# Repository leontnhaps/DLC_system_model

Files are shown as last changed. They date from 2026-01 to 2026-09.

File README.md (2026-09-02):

# Camera-Guided Multi-Receiver Optical Wireless Power Transfer Testbed

<p align="center">
  <b>Receiver Detection · Multi-Object Tracking · Laser Pointing · Charging Scheduling</b>
</p>

This repository presents a research testbed for **laser-based Optical Wireless Power Transfer (OWPT)** in a single-transmitter, multi-receiver environment.

The platform integrates:

- camera-based receiver detection,
- pan-tilt workspace scanning,
- multi-object tracking,
- laser pointing,
- receiver-state recognition,
- time-division charging,
- and adaptive charging scheduling.

The system was developed as an experimental platform for research on **multi-receiver OWPT scheduling for wireless sensor and IoT networks**.

---

# 1. Overview

In a single-transmitter multi-receiver OWPT system, a laser transmitter must sequentially deliver energy to multiple receivers.

Because the available charging time is limited, the scheduling policy determines how much charging time is allocated to each receiver.

The research conducted with this platform was developed in two stages.

### Stage 1 — Receiver-State-Based Scheduling

The receiver battery state is represented using a **3-bit LED combination**.

The transmitter detects the receiver position and LED state through a camera and allocates more charging time to receivers with lower energy states.

```text
Receiver Scanning
        ↓
Receiver Detection
        ↓
Receiver Identification
        ↓
Battery-State Recognition
        ↓
Laser Pointing
        ↓
Charging-Time Allocation
        ↓
Sequential Optical Power Transfer
```

### Stage 2 — Battery and Energy-Transfer-Efficiency-Based Scheduling

Battery state alone does not represent the actual OWPT receiving condition.

Received optical power can vary due to:

- Tx–Rx distance,
- laser beam spreading,
- pointing error,
- and other optical channel conditions.

Therefore, the scheduling algorithm was extended to jointly consider:

```text
Battery State
      +
Energy Transfer Efficiency
      ↓
Priority Score
      ↓
Adaptive Charging-Time Allocation
```

---

# 2. System Architecture

The experimental platform follows a three-layer architecture.

```mermaid
graph LR

    GUI["PC GUI / Compute"]
    SERVER["Relay Server"]
    PI["Raspberry Pi Agent"]
    DRIVER["Pan-Tilt Driver"]
    CAMERA["Camera"]
    LASER["850-nm Laser"]

    RX1["Rx 1"]
    RX2["Rx 2"]
    RX3["Rx 3"]
    RXN["Rx N"]

    GUI -->|CTRL JSONL| SERVER
    SERVER -->|CTRL JSONL| PI

    PI -->|Events / Images| SERVER
    SERVER -->|Events / Images| GUI

    PI -->|UART| DRIVER
    PI -->|CSI| CAMERA
    PI -->|GPIO| LASER

    LASER --> RX1
    LASER --> RX2
    LASER --> RX3
    LASER --> RXN
```

The **PC** performs computational tasks including:

- image processing,
- YOLO inference,
- multi-object tracking,
- target position estimation,
- pointing control,
- and scheduling.

The **Raspberry Pi** controls:

- the camera,
- pan-tilt hardware,
- laser,
- IR-CUT module,
- and communication with the PC.

---

# 3. Experimental OWPT Testbed

<p align="center">
  
</p>

> `assets/testbed_overview.png`  
> Recommended image: experimental environment and Tx/Rx layout from the OWPT scheduling experiment.

The experimental OWPT system consists of:

### Transmitter

- laser power-transfer module,
- pan-tilt camera platform,
- camera,
- control unit,
- Raspberry Pi,
- and pointing controller.

### Receiver

Each receiver contains:

- photovoltaic cell,
- battery,
- retroreflective marker,
- battery-state LED module,
- and receiver electronics.

The transmitter identifies the position and state of each receiver using the camera and sequentially transfers optical power using time-division charging.

---

# 4. Receiver Scanning

The pan-tilt platform scans the target area using a predefined angular grid.

For each pan-tilt position, the system captures:

```text
LED ON Image
LED OFF Image
```

and calculates:

```text
Diff = |Image_ON - Image_OFF|
```

Differential imaging suppresses static background components and enhances receiver-related optical features.

The resulting image is processed by the receiver-detection algorithm.

---

# 5. Receiver Detection

Receiver candidates are detected using an **Ultralytics YOLO** model.

The current implementation supports:

- full-image inference,
- tiled inference,
- overlapping tiles,
- confidence filtering,
- Non-Maximum Suppression,
- and GPU acceleration when available.

The detection results contain:

```text
Bounding Box
Confidence
Class
Image Coordinate
Pan Angle
Tilt Angle
```

---

# 6. Multi-Object Tracking

A physical receiver may appear in multiple neighboring scan images.

Therefore, detections obtained from different pan-tilt positions must be associated with the same receiver.

The tracking module uses:

- HSV histogram features,
- grayscale histogram features,
- spatial grid-based feature extraction,
- cosine similarity,
- neighboring scan-frame candidates,
- and Hungarian assignment.

Each identified receiver is assigned a persistent:

```text
track_id
```

Similar tracks can also be merged after the scanning stage.

---

# 7. Target Position Estimation

After scanning, the detected image coordinates are mapped to pan and tilt angles.

For horizontal motion:

```text
cx = a · pan + b
```

For vertical motion:

```text
cy = e · tilt + f
```

where:

- `cx`, `cy` denote receiver image coordinates,
- `pan`, `tilt` denote transmitter angles.

The angle at which the receiver reaches the image center is estimated from the fitted relationships.

```text
Scan Detections
      ↓
Pixel-Angle Relationship
      ↓
Pan / Tilt Estimation
      ↓
Initial Target Point
```

This provides the coarse pointing position for each receiver.

---

# 8. Closed-Loop Laser Fine Pointing

After coarse pointing, the system performs closed-loop laser alignment.

The camera detects:

```text
Receiver Target Position
          +
Laser Spot Position
```

The pixel-domain error is calculated as:

```text
error_x = target_x - laser_x

error_y = target_y - laser_y
```

The error is converted into an angular correction:

```text
Δpan  = K_pan  × error_x

Δtilt = K_tilt × error_y
```

The process is repeated until the pointing error falls below the defined convergence threshold.

```text
Capture
   ↓
Detect Receiver
   ↓
Detect Laser
   ↓
Calculate Error
   ↓
Pan/Tilt Correction
   ↓
Repeat
```

<p align="center">
  
</p>

> Recommended image: pointing debug result showing the detected target, laser position, and pointing error.

---

# 9. Receiver-State Representation

Each receiver represents its battery state using three LEDs.

The LED states correspond to a 3-bit value:

```text
R B G
```

where:

```text
ON  = 1
OFF = 0
```

Therefore, eight discrete receiver states can be represented:

```text
000
001
010
011
100
101
110
111
```

with:

```text
000 → lowest state

111 → highest state
```

The transmitter identifies the LED combination using its camera.

---

# 10. Scheduling Methods

## 10.1 Round-Robin Scheduling

The conventional Round-Robin scheduler allocates the same charging time to every receiver.

For:

```text
N       = number of receivers
T_frame = scheduling-frame duration
```

the charging duration is:

```text
t_i = T_frame / N
```

Thus:

```text
Rx1 → Rx2 → Rx3 → ... → RxN
```

receives equal temporal access to the laser transmitter.

---

## 10.2 Receiver-State-Based Scheduling

The first proposed method allocates charging time according to the receiver state.

Let:

```text
d_i(k) ∈ {0, ..., 7}
```

represent the receiver's 3-bit state.

The charging coefficient is:

```text
b_i(k) = (8 - d_i(k)) / 8
```

A receiver with a lower state therefore obtains a larger charging coefficient.

The charging time is allocated as:

```text
               b_i(k-1)
t_i(k) = --------------------- × T_frame
          Σ b_j(k-1)
```

Thus:

```text
Lower receiver state
        ↓
Larger coefficient
        ↓
Longer charging duration
```

---

# 11. Experimental Evaluation of Receiver-State-Based Scheduling

The indoor experiment used four receivers.

| Parameter | Value |
|---|---:|
| Number of receivers | 4 |
| Tx–Rx distance | 4.5–6.0 m |
| Number of frames | 8 |
| Frame duration | 240 s |
| Initial states | 100 / 101 / 110 / 101 |

For Round-Robin:

```text
Rx1 = 60 s
Rx2 = 60 s
Rx3 = 60 s
Rx4 = 60 s
```

For the proposed scheduler:

```text
Rx1 = 80 s
Rx2 = 60 s
Rx3 = 40 s
Rx4 = 60 s
```

The lowest-state receiver therefore receives the longest charging duration.

---

## Battery-Voltage Experiment

<p align="center">
  
</p>

> Recommended image: normalized battery-voltage trajectories from the multi-receiver scheduling experiment.

The most significant difference was observed for **Rx1**, which had the lowest initial receiver state.

Approximate voltage change:

| Receiver | Round-Robin | Proposed |
|---|---:|---:|
| Rx1 | −5 mV | **+5 mV** |
| Rx2 | Similar trend | Similar trend |
| Rx3 | −5 mV | −10 mV |
| Rx4 | Similar trend | Similar trend |

Rx1 shows an approximately **10 mV difference** between the two scheduling strategies.

The proposed scheduler does not attempt to maximize the voltage of every receiver.

Instead, it redistributes the limited charging time to protect receivers with relatively low energy states and reduce imbalance among receivers.

---

# 12. Image-Based Energy Transfer Efficiency Model

The second research stage considers that charging efficiency differs between receivers even when their battery states are identical.

To estimate the energy-transfer condition, laser ON/OFF images are used.

The laser intensity distribution is modeled as an elliptical Gaussian beam:

```text
                      (u-u0)^2   (v-v0)^2
s(u,v) = exp[-2( ---------------- + ---------------- )]
                         wu^2         wv^2
```

Experimentally estimated mean beam radii:

```text
w_u = 118.14 px

w_v = 124.51 px
```

<p align="center">
  
</p>

The laser intensity incident on the PV-cell area can then be estimated from the camera image.

---

# 13. Regression-Based Received-Power Estimation

A regression model is used to estimate the relationship between image-based optical intensity and measured PV output voltage.

The adopted shifted quadratic model is:

```text
V_i = a(x_i - b)^2 + c
```

where:

- `x_i` is the image-based intensity value,
- `V_i` is the predicted PV voltage.

The fitted coefficients used in the study were approximately:

```text
a = 1.51
b = 0.01
c = 0.03
```

The predicted charging power is then calculated using the estimated voltage.

---

# 14. Battery and Energy-Transfer-Efficiency-Based Scheduling

The second proposed scheduler combines two factors:

```text
Battery State        → B_i

Transfer Efficiency  → C_i
```

The charging-efficiency coefficient is calculated from the inverse predicted charging power:

```text
          1 / P_i
C_i = ----------------
       Σ (1 / P_j)
```

The scheduling priority becomes:

```text
Score_i(k) = B_i(k-1) × C_i
```

and the charging duration is:

```text
                 Score_i(k)
t_i(k) = ----------------------------- × T_frame
           Σ Score_j(k)
```

Consequently, a receiver receives higher priority when it has:

```text
Low Battery State
        +
Low Energy Transfer Efficiency
```

This allows the scheduler to account not only for energy deficiency but also for differences in the actual optical receiving environment.

---

# 15. Simulation Results

The scheduling methods were compared using **First Node Death (FND)** as the network-lifetime metric.

FND is defined as the time at which the battery level of the first sensor node falls below the predefined threshold.

### Simulation Parameters

| Parameter | Value |
|---|---:|
| Number of sensor nodes | 4 |
| Monte-Carlo trials | 100 |
| Tx–Rx distance | 5–10 m |
| Battery capacity | 12960 J |
| FND threshold | 12.5% |
| Frame duration | 240 s |
| Node power consumption | 50 mW |

---

## Average First Node Death Time

<p align="center">
  
</p>

| Scheduling Method | Average FND |
|---|---:|
| No Charging | 3780 min |
| Round-Robin | 5286 min |
| Receiver-State-Based | 5352 min |
| **Battery + Transfer-Efficiency Proposed** | **5553 min** |

The proposed method achieved the longest average network lifetime.

Relative improvement:

```text
vs. No Charging
+46.9%

vs. Round-Robin
+5.1%

vs. Receiver-State-Based Scheduling
+3.8%
```

This result shows that incorporating the actual energy-transfer condition into scheduling can improve network lifetime beyond a scheduler based only on receiver state.

---

# 16. Research Progression

The overall research progression implemented in this repository can be summarized as:

```text
Equal Charging
Round-Robin
      ↓
Receiver-State Recognition
      ↓
Receiver-State-Based Scheduling
      ↓
Image-Based Beam Modeling
      ↓
Energy Transfer Efficiency Estimation
      ↓
Battery + Efficiency Scheduling
```

The system therefore evolved from a simple time-division OWPT testbed into a camera-guided scheduling platform capable of considering both:

```text
Receiver Energy State
           +
Physical OWPT Transfer Condition
```

---

# 17. Repository Structure

```text
.
├── Com/
│   ├── Com_main.py
│   ├── app/
│   ├── infra/
│   ├── ui/
│   ├── vision/
│   ├── workflows/
│   ├── scheduling/
│   └── tests/
│
├── Server/
│   └── Server_main.py
│
├── Raspberrypi/
│   └── Rasp_main.py
│
├── Target/
│   └── RX/
│       └── RX.ino
│
├── Experiments/
│   ├── detection/
│   ├── tracking/
│   ├── pointing/
│   ├── beam_model/
│   └── scheduling/
│
├── Docs/
│   ├── system_architecture.md
│   ├── hardware_setup.md
│   └── experiment_setup.md
│
├── assets/
│   ├── testbed_overview.png
│   ├── pointing_result.png
│   └── results/
│       ├── battery_voltage_comparison.png
│       ├── beam_intensity_model.png
│       └── fnd_comparison.png
│
├── requirements.txt
├── LICENSE
└── README.md
```

---

# 18. Main Software Modules

| Module | Function |
|---|---|
| PC GUI | System control and experiment interface |
| YOLO Detector | Receiver detection |
| MOT | Receiver identification across scan positions |
| Scan Controller | Pan-tilt scan and image processing |
| Pointing | Target-angle estimation |
| Fine Aiming | Closed-loop laser alignment |
| Scheduling | Multi-receiver charging control |
| Relay Server | PC–Raspberry Pi communication |
| Raspberry Pi Agent | Physical hardware control |

---

# 19. Requirements

## PC

```bash
pip install numpy scipy opencv-python pillow ultralytics
```

Additional packages may be required depending on the experiment configuration.

---

## Raspberry Pi

```bash
pip install pyserial
```

The Raspberry Pi environment must also provide:

```text
picamera2
RPi.GPIO
```

---

# 20. Quick Start

## Step 1 — Start Relay Server

```bash
python Server/Server_main.py
```

Default ports:

| Connection | Port |
|---|---:|
| Raspberry Pi Control | 7500 |
| Raspberry Pi Images | 7501 |
| GUI Control | 7600 |
| GUI Images | 7601 |

---

## Step 2 — Start Raspberry Pi Agent

```bash
python3 Raspberrypi/Rasp_main.py
```

---

## Step 3 — Start PC GUI

```bash
python Com/Com_main.py
```

The GUI provides interfaces for:

- scanning,
- preview,
- manual pan-tilt control,
- laser control,
- pointing,
- and scheduling.

---

# 21. Experimental Output

A scan session produces:

```text
captures/
└── scan_YYYYMMDD_HHMMSS/
    ├── captured images
    ├── scan_*_detections.csv
    └── similarity_log_live.txt
```

Typical detection data include:

```text
pan_deg
tilt_deg
cx
cy
w
h
conf
cls
track_id
```

Additional fields may contain:

- LED-state estimates,
- receiver-state information,
- final pointing coordinates,
- and other experimental measurements.

---

# 22. Key Research Contributions

This project demonstrates an integrated framework for:

1. **camera-guided detection of multiple optical-power receivers,**
2. **receiver identification during pan-tilt scanning,**
3. **automatic laser pointing,**
4. **visual receiver-state recognition,**
5. **adaptive time-division optical power scheduling,**
6. **image-based estimation of OWPT energy-transfer conditions,**
7. **and lifetime-oriented scheduling for wireless sensor networks.**

---

# 23. Future Work

Possible extensions include:

- dynamic receiver tracking,
- mobile receiver charging,
- UAV optical wireless power transfer,
- receiver-side PV orientation control,
- simultaneous lightwave information and power transfer,
- and learning-based transmitter / receiver control.

---

# License

This project is released under the MIT License.

See `LICENSE` for details.

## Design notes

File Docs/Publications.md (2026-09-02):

# 📚 작성 논문 (Publications)

본 프로젝트로 작성된 연구 논문 목록입니다.

---

## 1. 레이저 기반 에너지 전송을 위한 픽셀-각도 맵핑 방식의 Pan-Tilt 카메라 제어

**학회**: 한국통신학회 (KICS)  
**연도**: 2025  

**요약**:  
레이저 기반 무선 에너지 전송 시스템에서 픽셀 좌표와 Pan-Tilt 각도 간 맵핑을 통한 정밀 제어 기법에 대한 연구입니다. 선형 회귀 기반 coarse alignment와 레이저 피드백 기반 fine adjustment 알고리즘이 제안되었습니다.

---

## 2. 광무선 전력 전송을 위한 Pan-Tilt 카메라 스캔 시스템에서 다중 객체 추적기법

**학회**: 한국통신학회 (KICS)  
**연도**: 2026  

**요약**:  
Pan-Tilt 카메라 기반 광무선 전력 전송(Optical Wireless Power Transfer) 시스템에서 스캔 중 다중 객체를 추적하는 기법에 대한 연구입니다. 헝가리안 알고리즘을 활용한 최적 매칭 및 특징 기반 객체 추적 알고리즘이 제안되었습니다.

---

## 3. Battery-Aware Scheduling for Multi-Receiver Laser Wireless Power Transfer in IoT Systems

**학회**: International Conference on Ubiquitous and Future Networks (ICUFN)  
**연도**: 2026  

**요약**:  
단일 송신기(Tx)와 다중 수신기(Rx)로 구성된 레이저 기반 OWPT 환경에서 각 Rx의 배터리 상태를 고려하는 충전 스케줄링 기법을 제안한 연구입니다. 각 Rx는 배터리 상태를 3-bit LED 조합으로 표시하고, Tx는 카메라를 이용해 이를 인식합니다. 이전 프레임에서 인식한 배터리 상태를 기반으로 현재 프레임의 충전 시간을 차등 할당하여, 배터리 상태가 낮은 Rx에 더 긴 충전 시간을 제공합니다. 실제 실내 레이저 기반 OWPT 테스트베드 실험을 통해 Round-Robin 방식보다 저배터리 Rx의 전압 저하를 완화하고 Rx 간 에너지 불균형을 줄일 수 있음을 확인하였습니다.

---

## 4. 무선 센서 네트워크를 위한 배터리 및 에너지 전송 효율 기반 레이저 무선 전력 전송 스케줄링 기법

**영문 제목**: Battery and Energy Transfer Efficiency Based Laser Wireless Power Transfer Scheduling for Wireless Sensor Networks  

**학회**: 한국통신학회 하계종합학술발표회 (KICS)  
**연도**: 2026  

**요약**:  
기존 배터리 상태 기반 OWPT 스케줄링을 확장하여, 각 센서 노드의 배터리 상태뿐만 아니라 실제 에너지 전송 효율을 함께 고려하는 충전 스케줄링 기법을 제안한 연구입니다. 레이저 ON/OFF 이미지의 차분과 Gaussian beam 모델을 이용해 각 수신기의 광 세기를 추정하고, 회귀 모델을 통해 PV cell의 출력 전압과 예상 충전 전력을 계산합니다. 이후 배터리 상태와 에너지 전송 효율을 결합한 우선도 점수를 기반으로 충전 시간을 동적으로 할당합니다. 시뮬레이션 결과 제안 방식은 평균 First Node Death(FND) 시간이 5553 min으로 나타났으며, Round-Robin 대비 약 5.1%, 기존 Battery-Aware 방식 대비 약 3.8%의 성능 향상을 보였습니다.

---

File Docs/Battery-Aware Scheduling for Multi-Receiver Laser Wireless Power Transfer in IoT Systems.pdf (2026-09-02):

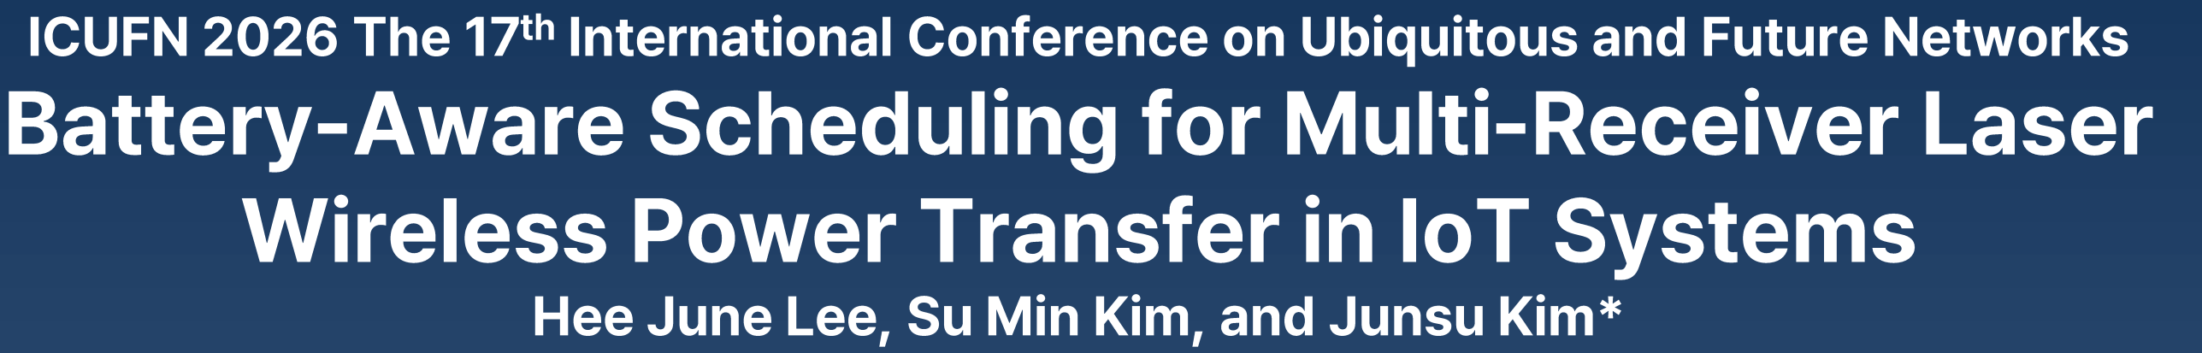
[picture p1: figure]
Wireless Power Transfer in IoT Systems

- Wireless Sensor Networks (WSNs)
- WSNs rely on battery - powered sensor nodes
- Battery depletion limits long -term network operation
- Optical Wireless Power Transfer (OWPT)
- OWPT can remotely supply energy to sensor nodes
- Laser - based OWPT enables selective power transfer due to its high directionality and narrow beam divergence
- Need for Multi- Receiver (Rx) Scheduling
- If Rxs have different battery states, low- battery Rxs should be charged with higher priority
- Therefore, efficient charging -time allocation is required to mitigate energy imbalance among Rxs

## Introduction

## ICUFN 2026 The 17 th International Conference on Ubiquitous and Future Networks

Battery -Aware Scheduling for Multi | - Receiver Laser
Hee June Lee, Su Min Kim, and Junsu | Kim*

## Tech University of Korea (TU Korea)

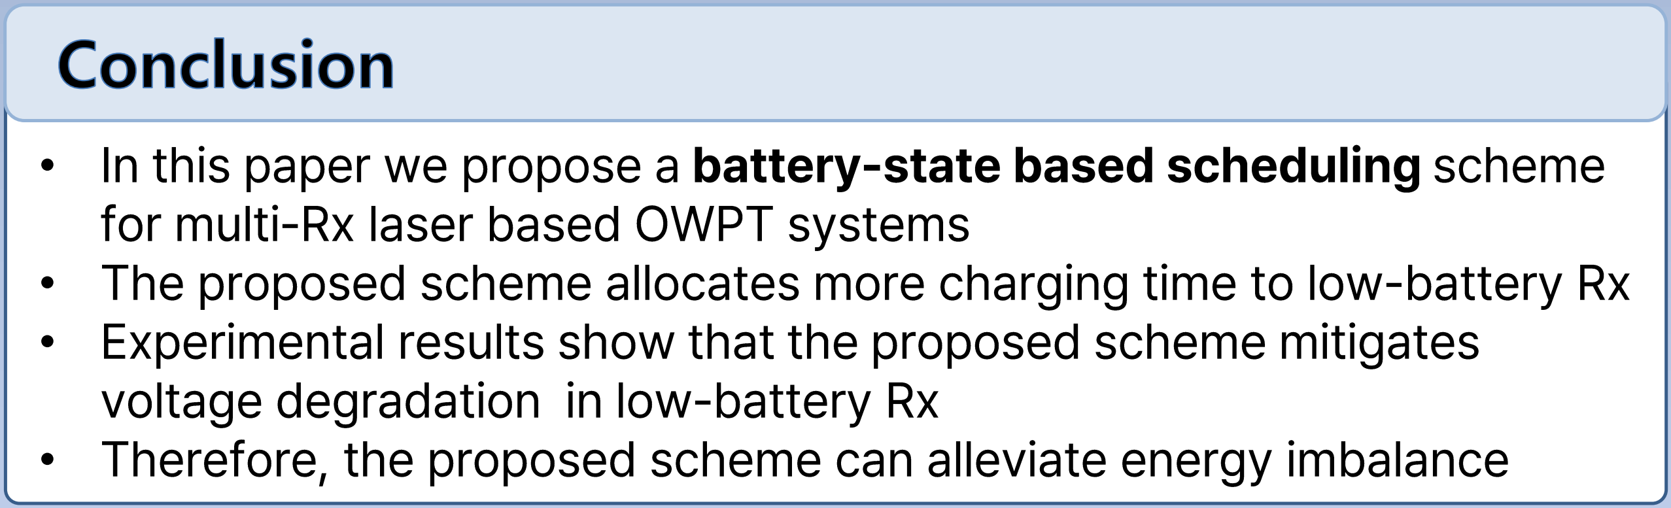
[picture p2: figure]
for multi-Rx laser based OWPT systems; voltage degradation; in low-battery Rx; Conclusion

This work was supported in part by the Institute of Information & Communications Technology Planning & Evaluation(IITP)-ICAN(ICT Challenge and Advanced Network of HRD) grant funded by the Korea government(Ministry of science and ICT)(IITP-2026-RS-2022-00156326, 50) and in part by the Commericalization Promotion Agency for R&D Outcomes (COMPA) funded by the Korea government (MSIT) (RS-2024-00456813).

- Laser - Based OWPT System Testbed
- The system consists of a | single fixed transmitter (Tx) | and multiple
fixed Rxs
- The Tx includes a laser power transfer module, a pan -tilt camera, and a control unit
- Each Rx consists of a PV cell, battery, retroreflective film, and 3 -blit LED module
(a) (b)
- System Operation
- The Tx identifies Rx positions and battery states using camera - based recognition
- Each Rx represents its battery state using a 3 - bit LED combination
- The operation consists of two stages, scanning and scheduling
- Time -division charging is performed, where only one Rx is charge at a time
(a) (b)

## System Model

Abstract
This work proposes a scheduling scheme for a singe | -transmitter (Tx) multi -receiver (Rx) laser -based optical wireless power trans | fer (OWPT) system. Each Rx represents
its battery state using a 3 -bit LED combination, which is recognized by the Tx through a camera. Based on the battery | -state info rmation obtained in the previous frame,
the charging time is adaptively allocated so that | Rxs with lower battery states receive more charging time. Experimental results show that proposed scheme mitigates
voltage degradation in low -battery Rxs and alleviates energy imbalance among | Rxs .
- Proposed Battery - State Based Scheduling
- Each Rx represents its | battery state using a 3 -blit LED combination
- The Tx recognizes the battery state of each Rx through | camera - based
recognition
- A lower battery state produces a larger charging coefficient
- Charging time is allocated according to the coefficient ratio in each frame
- Therefore, low-battery Rxs receive more charging time than high -battery Rxs

### - Conventional Round - Robin Scheduling

- Equal charging time is allocated to all Rxs in each frame
- However, it does not consider the battery state of each Rx

## Proposed Scheme

- Experimental Setup
- A total of four Rxs are evaluated using a dataset acquired from the implemented indoor laser - based OWPT testbed
- The Tx -Rx distances range from 4.5 m to 6 m
- The frame duration is set to 240 s, and 8 frames are evaluated
- The initial 3 -bit battery states are set to 100, 101, 110, and 101
- Charging - Time Allocation
- In the round -robin scheme , 60 s is allocated to each Rx
- In the proposed scheme , charging times of 80, 60, 40 and 60 s are allocated according to the battery state
- Rx1 is allocated the longest charging time because it had the lowest initial battery state
- Result Analysis
- In the proposed scheme, Rx1 voltage | increased by approximately 5 mV
- In the round -robin scheduling, Rx1 voltage | decreased by approximately

### 5 mV

- The proposed scheme mitigates voltage degradation in the low | -battery
- This result shows that adaptive charging | -time allocation can alleviate
energy imbalance | among Rxs

## Performance Evaluation

Laser wavelength | 850 nm
Number of Rxs | 4
Tx -Rx distance for each Rx | 4.5~6 m
Number of frames | 8
Duration of a single frame | 240 s
- In this paper we propose a | battery -state based scheduling | scheme
- The proposed scheme allocates more charging time to low | -battery Rx
- Experimental results show that the proposed scheme mitigates
- Therefore, the proposed scheme can alleviate energy imbalance

Table. 1. System parameters .

Fig. 1. Photographs of the Tx and Rx modules used in the experimental laser - based OWPT testbed : (a) Tx, (b) Rx .

Fig. 2. Experimental laser - based OWPT testbed: (a) Photograph of the indoor test environment, (b) Layout of the experimental laser based OWPT testbed.

Fig. 3. Comparison of normalized battery | - voltage trajectories of
the Rxs under the proposed and round | -robin scheduling schemes.

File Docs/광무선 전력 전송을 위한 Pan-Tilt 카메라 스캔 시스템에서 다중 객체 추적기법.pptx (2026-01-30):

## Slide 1

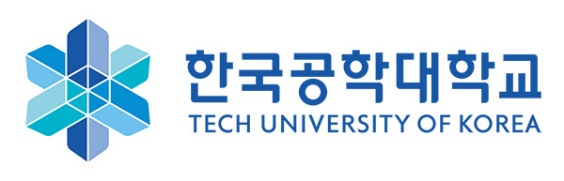
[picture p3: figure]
한국산업기술대학교, 한국공학대학교로 교명 변경하고 비전 선포식 개최-아이씨엔매거진

광무선 전력 전송을 위한 Pan-Tilt 카메라
스캔 시스템에서 다중 객체 추적 기법

2026-02-06
이희준, 빈경민, 김수민, 김준수*
gmlwns2279@tukorea.ac.kr
Dept. of IT Semiconductor Convergence Engineering, TUK
Intelligent Connected-Things (ICon) Lab

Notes: 안녕하세요. '광무선 전력 전송을 위한 Pan-Tilt 카메라 스캔 시스템에서 다중 객체 추적 기법'에 대해 김준수 교수님 지도학생 석사 1년차 이희준입니다. 발표 시작하겠습니다.

## 목차

- 서론
- System model
- 제안하는 기법
- 스캔 토폴로지 기반 인접 후보군 탐색 기법
- 정보 보존형 격자 히스토그램 기법

- 성능평가
- 결론

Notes: 목차입니다.

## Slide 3

- 문제 정의
  - 광무선 전력 전송(OWPT)시 수신부의 정확한 위치 파악 및 지속적 추적 필수[1].
  - 넓은 공간을 저비용으로 커버하기위한 pan-tilt 카메라 사용[2].
  - 넓은 영역 커버를 위해 pan-tilt를 높은 각도로 스캔 시, 프레임 간 타겟 위치가 불연속적으로 급변함.
  - 기존 다중 객체 추적 알고리즘(SORT)는 IoU기반 추적 알고리즘이기에 본 시스템에서 추적을 실패함[3].
- 해결 방안
  - 스캔 토폴로지 기반 인접 후보군 탐색 기법 : 물리적 위치 대신 스캔 경로의 논리적 인접성을 활용한 후보군 탐색 기법 제안.
  - 정보 보존형 격자 히스토그램 기법 : 시점 변화 및 정보 보존에 강인하도록 격자 분할 기반의 색상/형태 히스토그램 코사인 매칭 적용.

[1] S. A. H. Mohsan, H. Qian, and H. Amjad, "A Comprehensive Review of Optical Wireless Power Transfer Technology," Frontiers of Information Technology & Electronic Engineering, vol. 24, no. 6, pp. 767-800, June 2023.
[2] H. J. Lee, G. M. Been, S. M. Kim, and J. Kim, “Pan-Tilt Camera Control with Pixel-Angle Mapping for Laser Energy Transfer”, in Proc. KICS Fall Conf., Nov. 2025.
[3] A. Bewley, Z. Ge, L. Ott, F. Ramos, and B. Upcroft, "Simple online and realtime tracking," in Proc. IEEE ICIP, Sep. 2016.

서론

1

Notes: 최근 IoT 기기의 전원 공급을 위해 광무선 전력 전송(OWPT) 기술이 주목받고 있습니다.
이 시스템의 핵심은 수신부의 위치를 정확히 파악하고 지속적으로 추적하는 것입니다.
저희는 넓은 공간을 저비용으로 커버하기 위해 Pan-Tilt 카메라를 도입했습니다.
다중 타겟인 상태에서, 넓은 영역을 15도씩 빠르게 스캔하다 보니, 프레임 간 타겟의 위치가 불연속적으로 급변하는 문제가 발생했습니다.
이로 인해 기존의 위치 기반 추적 알고리즘인 SORT 등은 추적에 실패하게 됩니다.
이를 해결하기 위해 저희는 물리적 거리 대신 스캔 토폴로지 기반 인접 후보군 탐색 기법 , 정보 보존형 격자 히스토그램 기법을 제안합니다.

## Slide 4

System model

송신부
- Pan-tilt 구동부, RGB 카메라, LED 모듈, 레이저 모듈 로 구성.
- Boustrophedon 패턴을 따라 15° 의 간격 으로 스캔 진행.
수신부
- 인식을 위한 빨간색 재귀반사필름, 에너지 변환을 위한 Solar cell 로 구성.
- 송신부로 부터 5~10 m 거리내에 4개 무작위 배치.

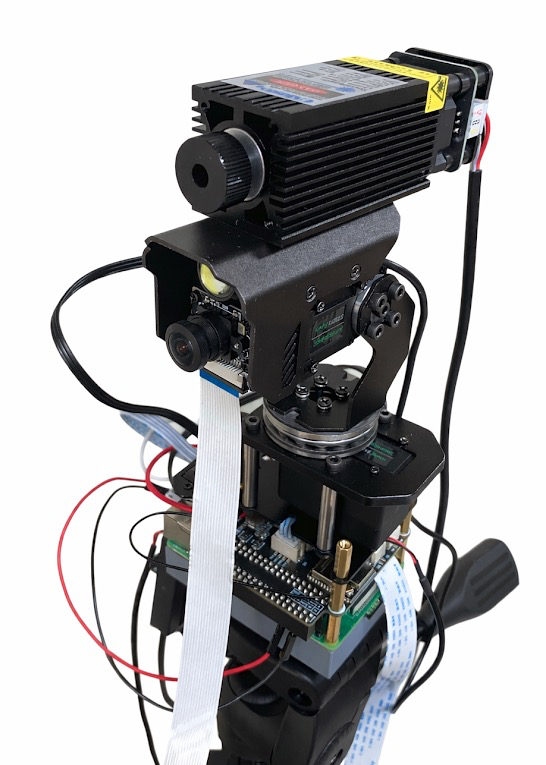
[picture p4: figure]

그림 1. 송신부

2

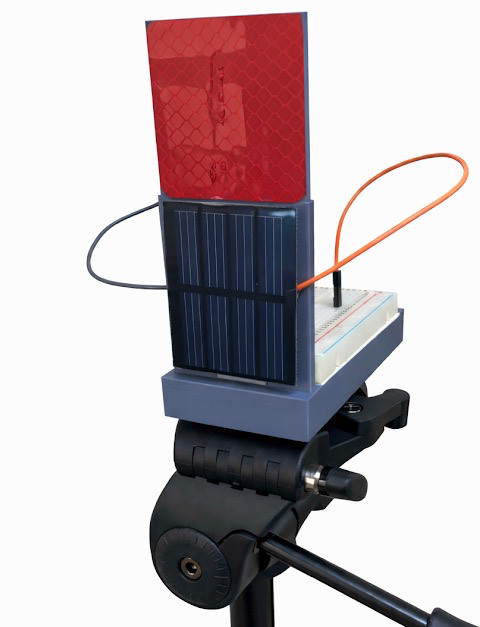
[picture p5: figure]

그림 2. 수신부

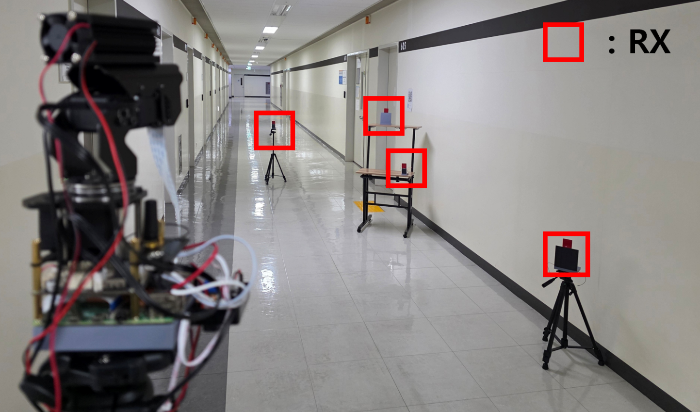
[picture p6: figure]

그림 3. 시스템 모델

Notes: 본 연구의 시스템 모델입니다.
송신부는 Pan-Tilt 구동부 위에 RGB 카메라와 레이저, LED 모듈이 결합된 형태이며,
효율적인 탐색을 위해 지그재그 형태인 Boustrophedon(부스트로페돈) 패턴으로 15도씩 이동하며 스캔합니다.
수신부는 5~10m 거리에 무작위로 배치되어 있으며,
인식을 돕기 위한 빨간색 재귀반사필름과 에너지를 전환 할 Solar cell 로 구성되어 있습니다.
수신부를 검출하는 방법은 사전에 재귀반사필름을 학습시킨 Yolo 모델을 통해 검출합니다.

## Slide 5

■ 스캔 토폴로지 기반 인접 후보군 탐색 기법

- 기존 알고리즘은 후보군의 최대 개수(max age)를 정한 후 후보군 생성.
- 수신부가 정적이므로 인접한 pan,tilt 일때 탐지될 확률이 높음.
- 최대 개수를 지정하는 대신 스캔 토폴로지의 인접성을 통한 비교 후보군 지정.
- 현재 스캔 인덱스를 (Pan_t ,Tilt_t ) 라 고 할때, 후보군 생성.
S={(Pan_(t−1) ,Tilt_t ),(Pan_t ,Tilt_(t−1) ),(Pan_(t−1) ,Tilt_(t−1) ),(Pan_(t−2) ,Tilt_t ),(Pan_(t+1) ,Tilt_(t−1) )}

3

스캔 토폴로지 기반 인접 후보군 탐색 기법

4 | 3 | 2 | 1 | (Pan_t ,Tilt_t )
5 | 6 | 7 | 8 | 9 | 10

그림 4. Max age =10 인 기존 알고리즘 후보군

| | (Pan_(t−2) ,Tilt_t ) | (Pan_(t−1) ,Tilt_t ) | (Pan_t ,Tilt_t )
| | | (Pan_(t−1) ,Tilt_(t−1) ) | (Pan_t ,Tilt_(t−1) ) | (Pan_(t+1) ,Tilt_t )

그림 5. 제안하는 기법의 후보군

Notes: 스캔 토폴로지 기반 인접 후보군 탐색 기법 입니다.
기존의 MOT 알고리즘은 최대 프레임 개수에 제한을두고 후보군을 비교하는 방식으로 진행이 됩니다.
저희 시스템에선 타겟이 정적임에 따라, 탐지가 되었을때 근처 pan, tilt 에서 탐지가 되었을 확률이 높습니다.
따라서 최대개수를 지정해 프레임을 비교하는 것이아니라 스캔 토폴로지의 인접성을 이용하여 후보군을 지정하여 비교 프레임 개수를 효율적으로 줄일 수 있습니다.
지정하는 후보군은 tilt 값이 그대로고 pan 값을 조정한 전프레임과 전전프레임, tilt 값을 조정한 토폴로지 기준 아래 프레임, pan, tilt 값을 둘다 조정한 대각선프레임 총 5개의 후보군을 지정하여 비교를 합니다.

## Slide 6

■ 1. 프레임 촬영 , 2. 수신부 탐지

4

정보 보존형 격자 히스토그램 기법

1. 프레임 촬영

2. 수신부 탐지

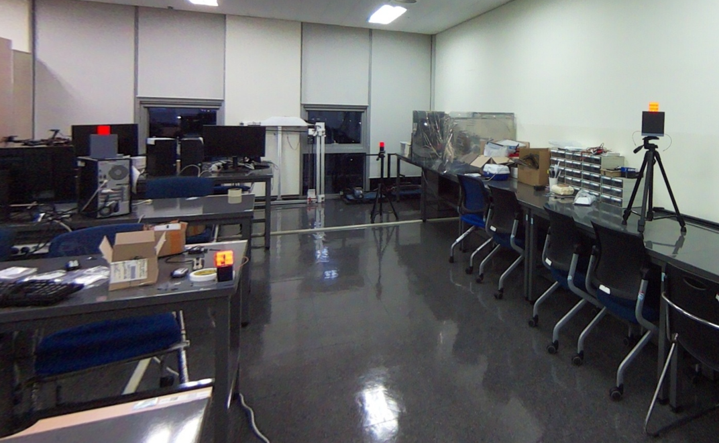
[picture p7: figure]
실내, 가구, 벽, 컴퓨터이(가) 표시된 사진 AI 생성 콘텐츠는 정확하지 않을 수 있습니다.

그림 6. 프레임 촬영 및 수신부 탐지

3. ROI

4. 격자 생성

5. 히스토그램 추출

6. 비교 및 최적 매칭

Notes: 비교하는 방식은 총 6단계로 이루어져 있습니다. 프레임 촬영, 객체 탐지, ROI, 격자 생성, 히스토그램추출 , 비교 및 최적 매칭 순으로 이루어 집니다.
우선 프레임촬영과 수신부탐지입니다.
각 지정된 스캔지점에서 촬영을하여 수신부를 탐지합니다.
재귀반사필름을 학습한 모델, yolo를 이용하여 수신부를 탐지합니다.
수신부가 탐지되지 않으면 스캔 경로에따라 프레임촬영을 이어서 합니다.

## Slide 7

■ 3. ROI , 4. 격자 생성

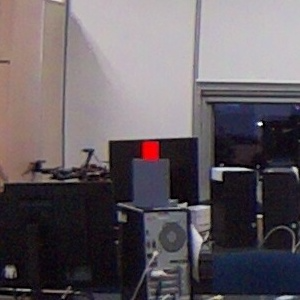
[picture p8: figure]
실내, 라우드스피커, 벽, 오디오 장비이(가) 표시된 사진 AI 생성 콘텐츠는 정확하지 않을 수 있습니다.

그림 7. 300x300 ROI

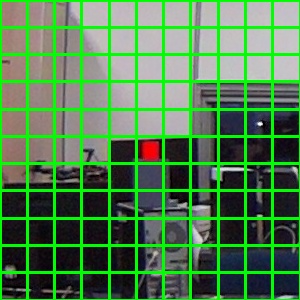
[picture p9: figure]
사각형, 스크린샷, 다채로움, 예술이(가) 표시된 사진 AI 생성 콘텐츠는 정확하지 않을 수 있습니다.

그림 8. 11x11 격자 생성

- ROI : 수신부 및 배경 정보를 추출하기위한 ROI 생성.
- 격자 생성 : 정보 추출 시, 공간정보를 보존하기 위한 격자 생성.

5

정보 보존형 격자 히스토그램 기법

1. 프레임 촬영

2. 수신부 탐지

3. ROI

4. 격자 생성

5. 히스토그램 추출

6. 비교 및 최적 매칭

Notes: ROI, 격자생성 단계입니다.
정보를 추출하기위해 탐지된 수신부의 중심으로 부터 300x300 ROI 를 합니다.
이후 ROI 에서부터 정보를 추출할때 공간정보를 보존하기위한 11x11 의 격자를 생성합니다.

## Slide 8

■ 5. 히스토그램 추출, 6. 비교 및 최적 매칭

- 히스토그램 추출 : 격자별 HSV, Grayscale 에서의 히스토그램 추출 및 특징 벡터 생성.
- 코사인 유사도 : 특징 벡터 간의 각도를 계산하여 유사도 측정.
Similarity(A,B) =(V_A ∙V_B)/(|V_A ||V_B |)
- 최적화 : 헝가리안 알고리즘을 사용하여 최적 매칭 수행[4].
- ID Assignment : 코사인 유사도 값이 일정 값 보다 낮을 때, 새로운 ID 부여.

[4] H. W. Kuhn, "The Hungarian method for the assignment problem," Naval Research Logistics Quarterly, vol. 2, no. 1-2, pp. 83-97, 1955. 6

정보 보존형 격자 히스토그램 기법

1. 프레임 촬영

2. 수신부 탐지

3. ROI

4. 격자 생성

5. 히스토그램 추출

6. 비교 및 최적 매칭

히스토그램 추출

특징 벡터

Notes: 나눠진 격자별로 비교를 위해 히스토그램을 추출하는데 추출하는영역은
HSV 에서의 HS, Grayscale 에서의 히스토그램을 추출하여 하나의 특징벡터로 결합합니다.
H(0~360 , 8) S(0~100 , 4), Gray(0~255, 16)
이후 스캔 토폴로지에 따른 후보군에서 뽑은 특징

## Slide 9

■ 평가지표

- IDSW(ID Switch) - 추적하는 타겟의 ID가 바뀌는 횟수
- ID Purity - 하나의 ID에서 가장 많은 빈도의 타겟이 차지하는 비율
- MOTA(MOT Accuracy) - 탐지성능과 IDSW를 종합한 표준 정확도. - MOTA= 1 − (∑_t (FN_t + FP_t + IDSW_t ))/(∑_t GT^t).
- AssA(Association Accuracy) - 올바른 ID가 유지된 시간 비율의 가중평균.

7

성능평가

t : 프레임 인덱스.
FN_t : t 에 서의 미검출 수.
FP_t : t 에 서의 오검출 수.
IDSW_t : ID 스위칭 수.
GT^t : t 에 존재하는 실제 타겟의 총 수.

1

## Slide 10

■ 검증 결과

- 실내 환경에서 5-10m 거리에 수신부를 배치하여 획득한 데이터 셋 활용.
- 표2는 KITTI test set 에대한 MOTA 결과표로 90%대의 결과를 보여줌[5].
- 제안하는 기법은 보다 쉬운 환경임에따라 보다 높은 MOTA 기록.

[5] X. Wang et al., "MCTrack: A Unified 3D Multi-Object Tracking Framework for Autonomous Driving," 2025 IEEE/RSJ International Conference on Intelligent Robots and Systems (IROS), Hangzhou, China, 2025 8

성능 평가

파라미터 | 값
실제 타겟 수 | 4 개
식별 타겟 수 | 10 개
MOTA(↑) | 94.5%
IDSW(↓) | 6회
ID Purity(↑) | 100%

표1. 검증결과

기법 | MOTA
MCTrack | 91.62%
CasTrack | 91.91%
RAM | 91.61%
OC-SORT | 90.28%
BiTrack | 91.52%

표2. 타 Method MOTA

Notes: 성능 평가입니다.
검증결과 실내 환경에서 4개의 수신부를 5~10m 거리에 배치하여 획득한 데이터셋으로 검증을 하였고.
결과는 표1과 같습니다.
표2는 타 MOT Mehod의 MOTA 결과인데 KITTI test set 에대한 지표입니다.
Kitti test set은 자율주행 을 위한 데이터 셋입니다.
저희가 제안하는 방식은 보다 쉬운환경임에따라 보다 높은 MOTA 결과를 얻은것을 확인할 수 있습니다.

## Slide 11

Method | ID Purity(↑) | IDSW(↓) | AssA(↑) | MOTA(↑)
스캔 토폴로지 기반 인접 후보군, 격자(11x11) | 100% | 6회 | 0.76 | 94.5%
스캔 토폴로지 기반 인접 후보군, 격자(5x5) | 75.5% | 1회 | 0.73 | 99.1%
스캔 토폴로지 기반 인접 후보군, 격자 미적용 | 32.7% | 2회 | 0.25 | 98.2%
Max age = 5, 격자(11x11) | 100% | 6회 | 0.58 | 94.5%
Max age = 5, 격자 미적용 | 31.8% | 2회 | 0.24 | 98.2%

- 격자의 정보보존 : 단일 히스토그램(Grid 미적용)은 정보의 부족으로 인한 객체 구분 실패로 인해, ID Purity매우 낮은 값 도출.
- 토폴로지 기반 후보군 : 트랙 파편화를 억제하여 높은 AssA 도출.
- 병합 오류 방지 : 일부 높은 MOTA 값은 낮은 비교 성능으로 인한 ID 병합에 의한 값.

9

성능 평가

표3. 제안 기법의 파라미터별 성능 평가

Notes: 제안 기법을 검증하기 위한 결과표입니다.
격자가 미적용되거나 조금 낮은 방식을 적용한 결과를보면 MOTA가 매우 높에 나온것을 확인할 수있습니다.
이는 격자 의 분류가 낮거나 미적용으로인해 객체의 정보부족으로 서로다른 객체를 구분하지 못하고 하나로 병합했기에 ID SW 값자체가 낮아 나온 결과입니다. 이는 ID Purity 를 보시면 객체를 구분하지못하고 병합해버려 비교적 낮은 값들이 나온것을 확인할수 있습니다.
스캔 토폴로지 기반 후보군을 적용을 비교하면 격자 미적용시에는 AssA 값이 차이가 많이 나지않지만 이는 객체를 비교하지 못하여 나온것이고, 격자 적용시를 비교하면 AssA 값이 오른것을 확인할 수 있습니다. 이는 동일하게 5개의 후보군을 비교를 했지만 스캔 토폴로지 기반 후보군이 보다 우수한 비교 후보군을 생성해 파편화를 억제한것을 확인할수있습니다.

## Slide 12

■ 결론, 향후 연구

결론
- 본 논문은 pan-tilt 카메라를 활용한 레이저 기반의 무선 전력 전송 시스템에서 다중 객체 추적 기법을 제안함.
- 스캔 토폴로지 기반 인접 후보군 탐색 기법을 통해 급격한 시점 변화에도 트랙 파편화를 억제하고 추적 안정성 확보.
- 격자 기반 히스토그램 코사인 유사도를 통해 시점/외형 변화에 강인한 추적 성능 확보.
- 실내 환경에서의 검증 결과 MOTA 94.5% 달성으로 안정적 추적 확인.
향후 연구
- Target 설계를 통한 IoT 기기 충전 시스템 연구.
- 정적인 Target 이 아닌 동적인 Target 시스템 에서의 추가 기법 고안.

10

결론

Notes: 결론입니다.

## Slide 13

Thank you

2026-02-06
이희준, 빈경민, 김수민, 김준수*
gmlwns2279@tukorea.ac.kr
Dept. of IT Semiconductor Convergence Engineering, TUK
Intelligent Connected-Things (ICon) Lab

마무리

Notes: 감사합니다.

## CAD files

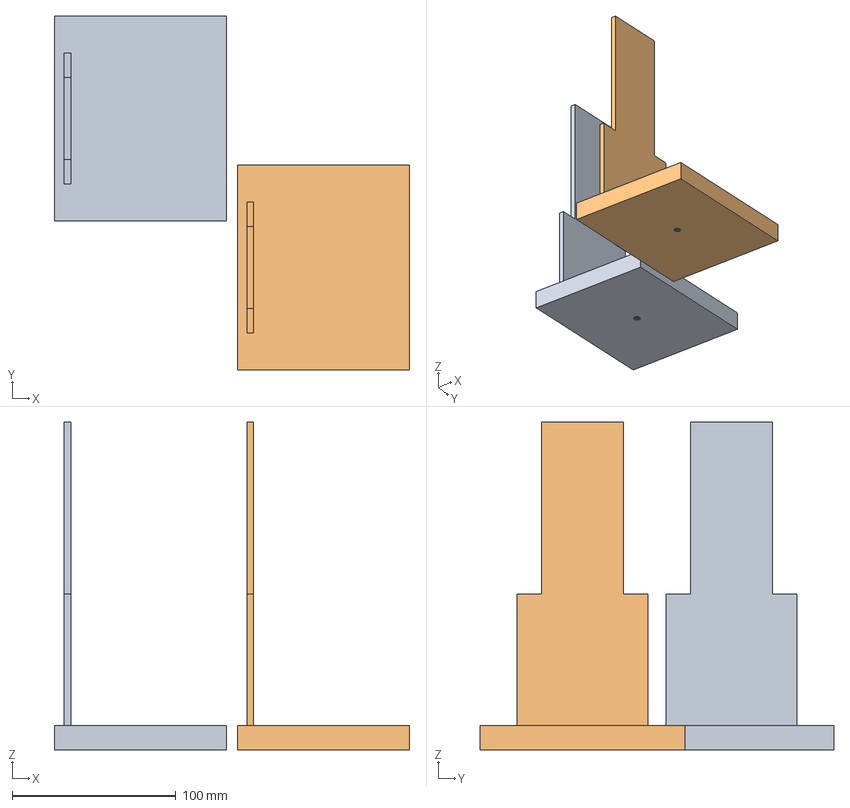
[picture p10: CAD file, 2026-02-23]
3D_printer/RX/8_8_RX/8_8_align.3mf
216.6 x 215.9 x 200.0 mm
Camera_LaserModule.stl x 2

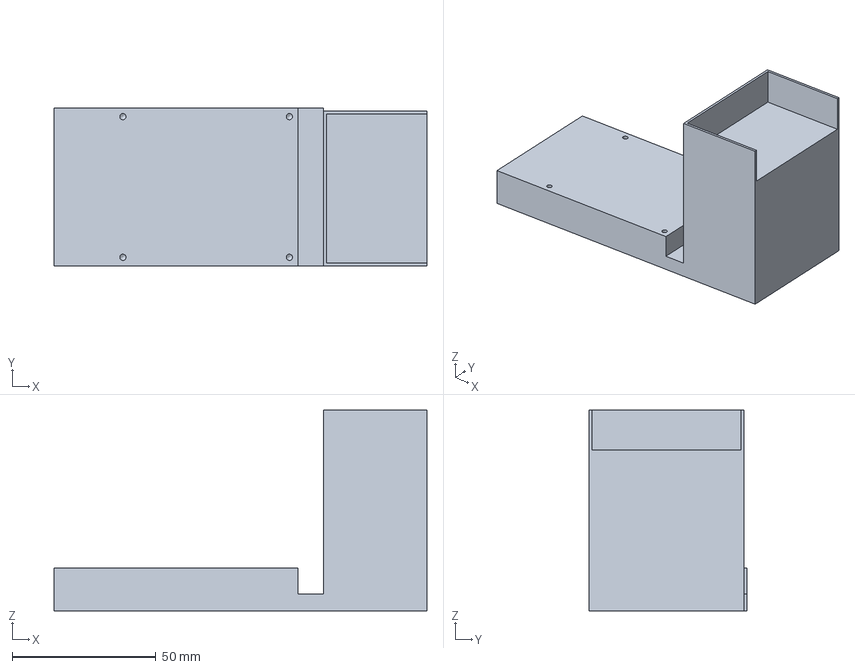
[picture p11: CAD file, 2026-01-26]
3D_printer/TX/TX_mount.3mf
129.9 x 55.0 x 70.0 mm

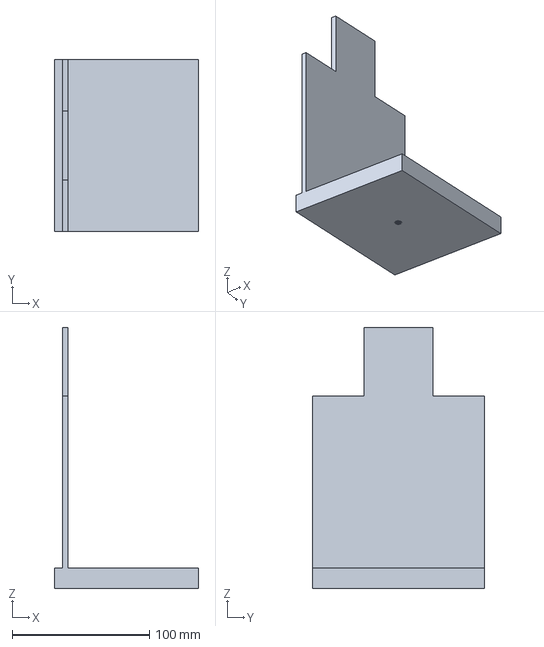
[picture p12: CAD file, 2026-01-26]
3D_printer/RX/12_12_RX/Target.3mf
105.0 x 125.1 x 190.0 mm

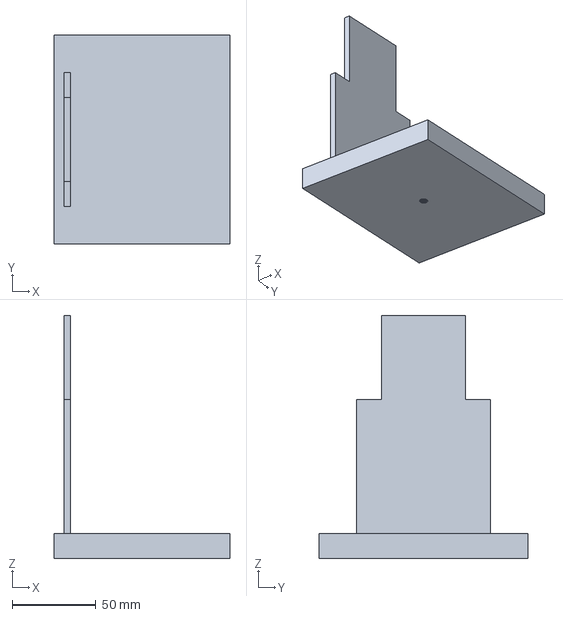
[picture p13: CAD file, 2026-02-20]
3D_printer/RX/8_8_RX/8_8test.3mf
105.0 x 125.0 x 145.0 mm

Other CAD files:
3D_printer/RX/12_12_RX/Target.gcode.3mf
3D_printer/RX/8_8_RX/8_8_align.gcode.3mf
3D_printer/TX/TX_mount.gcode.3mf
3D_printer/RX/8_8_RX/8_8.gcode.3mf
3D_printer/RX/8_8_RX/18_8test.gcode.3mf
3D_printer/RX/12_12_RX/Target.stl
3D_printer/TX/TX_mount.stl

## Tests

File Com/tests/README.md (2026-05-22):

# Com 테스트 실행 방법

아래 명령을 저장소 루트에서 실행하세요.

```bash
uv run python -m compileall Com
uv run python -m unittest discover -s Com/tests
```

개별 smoke/wrapper 테스트만 확인할 때는 필요한 파일을 직접 실행할 수 있습니다.

```bash
uv run python Com/tests/test_naming.py
uv run python Com/tests/test_router.py
uv run python Com/tests/test_scheduling_proposed.py
```

---

## 현재 `Com/` 구조

`Com/Com_main.py`는 GUI 실행 진입점이고, 대부분의 루트 모듈은 기존 import를 유지하기 위한 compatibility wrapper입니다. 실제 구현은 아래 패키지들에 나뉘어 있습니다.

- `app/`: 앱 상태, 설정, 메인 윈도우, 이벤트 핸들러, helper
- `infra/`: 이벤트 버스, 이미지 라우터, 네트워크 클라이언트, 프로토콜
- `ui/`: Tkinter preview frame 및 각 탭 UI
- `utils/`: 이름 파싱, UI thread helper 등 범용 유틸리티
- `vision/`: YOLO, MOT, scan controller, LED filter
- `workflows/`: Scan, Pointing, Scheduling workflow 경계
- `scheduling/`: RoundRobin/Proposed scheduling 알고리즘
- `tests/`: stdlib 기반 테스트

---

## 주요 확인 포인트

- GUI wrapper가 실제 구현 모듈을 그대로 re-export하는지
- `infra`, `ui`, `utils`, `vision`, `workflows`, `scheduling` 패키지 import가 깨지지 않는지
- `ScanWorkflow`, `SchedulingWorkflow`가 기존 controller/algorithm을 감싸는 방식으로 연결되어 있는지
- `RoundRobinScheduler`, `ProposedScheduler`의 기본 선택/할당 로직이 기대대로 동작하는지
- 테스트는 하드웨어 없이 실행 가능한 범위의 smoke/unit 검증에 집중하는지

---

## 하드웨어 적용 전 체크리스트

- [ ] `python Com/Com_main.py`로 GUI 실행
- [ ] Server 연결 정상
- [ ] Pi Agent 연결 정상
- [ ] Preview 프레임 수신 정상
- [ ] Scan 시작/중지 및 progress 업데이트 정상
- [ ] 이미지 저장, CSV 저장, similarity log 저장 정상
- [ ] Pointing target 계산 및 aiming loop 정상
- [ ] RoundRobin scheduling 동작 정상
- [ ] Proposed scheduling 동작 정상
- [ ] `cv2`, `numpy`, `scipy`, `PIL`, `ultralytics` 설치 확인
- [ ] `captures/` 저장 권한 확인

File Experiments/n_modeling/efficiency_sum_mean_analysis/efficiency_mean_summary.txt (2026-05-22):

======================================================================
PV efficiency summary using beam_integral_mean
======================================================================

Voltage column             : vol_load [V]
Integral column            : beam_integral_mean
Load resistor              : 100 ohm
Ambient voltage subtracted : 0.0175 V
Regression/fitting         : not applied in this script

Total rows                 : 69
Valid rows                 : 47

[Input intensity]
beam_integral_mean min/max/mean : 0.013070088 / 0.86925982 / 0.43149721

[Corrected voltage]
vol_load min/max/mean      : 0.02 / 1.248 / 0.3712766 V
vol_corr min/max/mean      : 0.0025 / 1.2305 / 0.3537766 V

[Electrical output]
I_calc min/max/mean        : 0.025 / 12.305 / 3.537766 mA
P_elec min/max/mean        : 6.25e-05 / 15.141302 / 2.6073472 mW

[Correlation only]
Pearson r: mean vs vol_corr : 0.91773441
Pearson r: mean vs P_elec   : 0.81646437

[Generated files]
CSV     : efficiency_mean.csv
Summary : efficiency_mean_summary.txt

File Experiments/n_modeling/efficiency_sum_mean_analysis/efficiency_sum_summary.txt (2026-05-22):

======================================================================
PV efficiency summary using beam_integral_sum
======================================================================

Voltage column             : vol_load [V]
Integral column            : beam_integral_sum
Load resistor              : 100 ohm
Ambient voltage subtracted : 0.0175 V
Regression/fitting         : not applied in this script

Total rows                 : 69
Valid rows                 : 47

[Input intensity]
beam_integral_sum min/max/mean : 412.11231 / 18458.869 / 5102.6093

[Corrected voltage]
vol_load min/max/mean      : 0.02 / 1.248 / 0.3712766 V
vol_corr min/max/mean      : 0.0025 / 1.2305 / 0.3537766 V

[Electrical output]
I_calc min/max/mean        : 0.025 / 12.305 / 3.537766 mA
P_elec min/max/mean        : 6.25e-05 / 15.141302 / 2.6073472 mW

[Correlation only]
Pearson r: sum vs vol_corr : 0.40209707
Pearson r: sum vs P_elec   : 0.33726171

[Generated files]
CSV     : efficiency_sum.csv
Summary : efficiency_sum_summary.txt

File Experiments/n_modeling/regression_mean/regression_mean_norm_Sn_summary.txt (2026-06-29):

======================================================================
MEAN / NORMALIZED S_N regression summary with 5 holdout points (normalized S_n)
======================================================================
Input CSV       : C:\Users\gmlwn\OneDrive\바탕 화면\ICon2학년\DLC_system_model\Experiments\n_modeling\efficiency_mean.csv
X column        : beam_integral_mean
Y column        : corrected voltage = vol_load - 0.0175
Total rows      : 69
Valid rows      : 47
Training rows   : 42
Holdout rows    : 5
Holdout indices : [45, 17, 20, 52, 19]

[Method]
The valid data range on the x-axis was divided into 5 intervals.
One data point was selected from each interval as holdout data.
The 5 holdout points were excluded from fitting.
Regression was performed using the remaining training data.

[Internal x normalization]
For numerical stability, regression uses normalized x:
S_n = (S - S_min_train) / (S_max_train - S_min_train)
Plots still use the original x-axis values.

[Model results]

----------------------------------------------------------------------
Model: linear
success       : True
S_min_train   : 0.0130700881
S_scale_train : 0.8561897319
train R^2     : 0.8360834027
train RMSE    : 0.1503041018
holdout R^2   : 0.8089636218
holdout RMSE  : 0.1492919689
Equation      : V = m*S_n + b
m = 1.1909487120
b = -0.2624198111

----------------------------------------------------------------------
Model: quadratic
success       : True
S_min_train   : 0.0130700881
S_scale_train : 0.8561897319
train R^2     : 0.8882701310
train RMSE    : 0.1240920652
holdout R^2   : 0.8246808408
holdout RMSE  : 0.1430187893
Equation      : V = a*S_n^2 + b*S_n + c
a = 1.2214356515
b = -0.1135317352
c = -0.0073577497

----------------------------------------------------------------------
Model: shifted_quadratic
success       : True
S_min_train   : 0.0130700881
S_scale_train : 0.8561897319
train R^2     : 0.8883211983
train RMSE    : 0.1240637032
holdout R^2   : 0.8284136935
holdout RMSE  : 0.1414880368
Equation      : V = a*(S_n - h)^2 + c
a = 1.1089766800
h = -0.0000000000
c = -0.0274866182

----------------------------------------------------------------------
Model: exponential_growth
success       : True
S_min_train   : 0.0130700881
S_scale_train : 0.8561897319
train R^2     : 0.8764411982
train RMSE    : 0.1304957032
holdout R^2   : 0.8120744559
holdout RMSE  : 0.1480714455
Equation      : V = A*(exp(k*S_n) - 1) + c
A = 0.1998927111
k = 1.9299992934
c = -0.0718547834

[Best model by holdout RMSE]
1. shifted_quadratic: holdout RMSE=0.1414880368, train R^2=0.8883211983
2. quadratic: holdout RMSE=0.1430187893, train R^2=0.8882701310
3. exponential_growth: holdout RMSE=0.1480714455, train R^2=0.8764411982
4. linear: holdout RMSE=0.1492919689, train R^2=0.8360834027
======================================================================

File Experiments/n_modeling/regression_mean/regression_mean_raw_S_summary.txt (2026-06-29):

======================================================================
MEAN / RAW S regression summary with 5 holdout points (raw S without S_n normalization)
======================================================================
Input CSV       : C:\Users\gmlwn\OneDrive\바탕 화면\ICon2학년\DLC_system_model\Experiments\n_modeling\efficiency_mean.csv
X column        : beam_integral_mean
Y column        : corrected voltage = vol_load - 0.0175
Total rows      : 69
Valid rows      : 47
Training rows   : 42
Holdout rows    : 5
Holdout indices : [45, 17, 20, 52, 19]

[Method]
The valid data range on the x-axis was divided into 5 intervals.
One data point was selected from each interval as holdout data.
The 5 holdout points were excluded from fitting.
Regression was performed using the remaining training data.

[No internal x normalization]
Regression uses the original x value directly:
S = original beam integral value
No S_n = (S - S_min)/(S_max - S_min) transformation is used.

[Model results]

----------------------------------------------------------------------
Model: linear
success       : True
S_min_train   : 0.0130700881
S_scale_train : 0.8561897319
train R^2     : 0.8360834027
train RMSE    : 0.1503041018
holdout R^2   : 0.8089636218
holdout RMSE  : 0.1492919689
Equation      : V = m*S + b
m = 1.3909869128
b = -0.2806001326

----------------------------------------------------------------------
Model: quadratic
success       : True
S_min_train   : 0.0130700881
S_scale_train : 0.8561897319
train R^2     : 0.8882701310
train RMSE    : 0.1240920652
holdout R^2   : 0.8246808397
holdout RMSE  : 0.1430187898
Equation      : V = a*S^2 + b*S + c
a = 1.6662132098
b = -0.1761562842
c = -0.0053400008

----------------------------------------------------------------------
Model: shifted_quadratic
success       : True
S_min_train   : 0.0130700881
S_scale_train : 0.8561897319
train R^2     : 0.8883211982
train RMSE    : 0.1240637032
holdout R^2   : 0.8284136934
holdout RMSE  : 0.1414880369
Equation      : V = a*(S - h)^2 + c
a = 1.5128030220
h = 0.0130700881
c = -0.0274866182

----------------------------------------------------------------------
Model: exponential_growth
success       : True
S_min_train   : 0.0130700881
S_scale_train : 0.8561897319
train R^2     : 0.8764411304
train RMSE    : 0.1304957389
holdout R^2   : 0.8120741409
holdout RMSE  : 0.1480715695
Equation      : V = A*(exp(k*S) - 1) + c
A = 0.1940867521
k = 2.2541861570
c = -0.0776573483

[Best model by holdout RMSE]
1. shifted_quadratic: holdout RMSE=0.1414880369, train R^2=0.8883211982
2. quadratic: holdout RMSE=0.1430187898, train R^2=0.8882701310
3. exponential_growth: holdout RMSE=0.1480715695, train R^2=0.8764411304
4. linear: holdout RMSE=0.1492919689, train R^2=0.8360834027
======================================================================

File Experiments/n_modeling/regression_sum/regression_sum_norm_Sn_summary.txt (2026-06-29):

======================================================================
SUM / NORMALIZED S_N regression summary with 5 holdout points (normalized S_n)
======================================================================
Input CSV       : C:\Users\gmlwn\OneDrive\바탕 화면\ICon2학년\DLC_system_model\Experiments\n_modeling\efficiency_sum.csv
X column        : beam_integral_sum
Y column        : corrected voltage = vol_load - 0.0175
Total rows      : 69
Valid rows      : 47
Training rows   : 42
Holdout rows    : 5
Holdout indices : [53, 32, 63, 58, 66]

[Method]
The valid data range on the x-axis was divided into 5 intervals.
One data point was selected from each interval as holdout data.
The 5 holdout points were excluded from fitting.
Regression was performed using the remaining training data.

[Internal x normalization]
For numerical stability, regression uses normalized x:
S_n = (S - S_min_train) / (S_max_train - S_min_train)
Plots still use the original x-axis values.

[Model results]

----------------------------------------------------------------------
Model: linear
success       : True
S_min_train   : 412.1123146755
S_scale_train : 11356.4084281734
train R^2     : 0.2690494755
train RMSE    : 0.3210253748
holdout R^2   : -4.6434740968
holdout RMSE  : 0.7056364621
Equation      : V = m*S_n + b
m = 0.9787354156
b = -0.0187392971

----------------------------------------------------------------------
Model: quadratic
success       : True
S_min_train   : 412.1123146755
S_scale_train : 11356.4084281734
train R^2     : 0.2690494754
train RMSE    : 0.3210253748
holdout R^2   : -4.6434741031
holdout RMSE  : 0.7056364625
Equation      : V = a*S_n^2 + b*S_n + c
a = 0.0000000000
b = 0.9787354162
c = -0.0187392973

----------------------------------------------------------------------
Model: shifted_quadratic
success       : True
S_min_train   : 412.1123146755
S_scale_train : 11356.4084281734
train R^2     : 0.2540678080
train RMSE    : 0.3242985791
holdout R^2   : -5.3211686724
holdout RMSE  : 0.7468036560
Equation      : V = a*(S_n - h)^2 + c
a = 0.0973795306
h = -4.5228282769
c = -2.0000000000

----------------------------------------------------------------------
Model: exponential_growth
success       : True
S_min_train   : 412.1123146755
S_scale_train : 11356.4084281734
train R^2     : 0.2556167497
train RMSE    : 0.3239616982
holdout R^2   : -5.2876275411
holdout RMSE  : 0.7448196909
Equation      : V = A*(exp(k*S_n) - 1) + c
A = 5.0000000000
k = 0.1787552317
c = -0.0094320314

[Best model by holdout RMSE]
1. linear: holdout RMSE=0.7056364621, train R^2=0.2690494755
2. quadratic: holdout RMSE=0.7056364625, train R^2=0.2690494754
3. exponential_growth: holdout RMSE=0.7448196909, train R^2=0.2556167497
4. shifted_quadratic: holdout RMSE=0.7468036560, train R^2=0.2540678080
======================================================================

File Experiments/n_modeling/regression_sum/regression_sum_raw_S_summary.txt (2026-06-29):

======================================================================
SUM / RAW S regression summary with 5 holdout points (raw S without S_n normalization)
======================================================================
Input CSV       : C:\Users\gmlwn\OneDrive\바탕 화면\ICon2학년\DLC_system_model\Experiments\n_modeling\efficiency_sum.csv
X column        : beam_integral_sum
Y column        : corrected voltage = vol_load - 0.0175
Total rows      : 69
Valid rows      : 47
Training rows   : 42
Holdout rows    : 5
Holdout indices : [53, 32, 63, 58, 66]

[Method]
The valid data range on the x-axis was divided into 5 intervals.
One data point was selected from each interval as holdout data.
The 5 holdout points were excluded from fitting.
Regression was performed using the remaining training data.

[No internal x normalization]
Regression uses the original x value directly:
S = original beam integral value
No S_n = (S - S_min)/(S_max - S_min) transformation is used.

[Model results]

----------------------------------------------------------------------
Model: linear
success       : True
S_min_train   : 412.1123146755
S_scale_train : 11356.4084281734
train R^2     : 0.2690494754
train RMSE    : 0.3210253748
holdout R^2   : -4.6434741053
holdout RMSE  : 0.7056364626
Equation      : V = m*S + b
m = 0.0000861835
b = -0.0542565931

----------------------------------------------------------------------
Model: quadratic
success       : True
S_min_train   : 412.1123146755
S_scale_train : 11356.4084281734
train R^2     : 0.2690494754
train RMSE    : 0.3210253748
holdout R^2   : -4.6434741053
holdout RMSE  : 0.7056364626
Equation      : V = a*S^2 + b*S + c
a = 0.0000000000
b = 0.0000861835
c = -0.0542565931

----------------------------------------------------------------------
Model: shifted_quadratic
success       : True
S_min_train   : 412.1123146755
S_scale_train : 11356.4084281734
train R^2     : 0.2540677998
train RMSE    : 0.3242985808
holdout R^2   : -5.3211693403
holdout RMSE  : 0.7468036954
Equation      : V = a*(S - h)^2 + c
a = 0.0000000008
h = -50950.9701979289
c = -2.0000000000

----------------------------------------------------------------------
Model: exponential_growth
success       : True
S_min_train   : 412.1123146755
S_scale_train : 11356.4084281734
train R^2     : 0.2556944336
train RMSE    : 0.3239447934
holdout R^2   : -5.2839267242
holdout RMSE  : 0.7446004630
Equation      : V = A*(exp(k*S) - 1) + c
A = 5.0000000000
k = 0.0000156482
c = -0.0418401070

[Best model by holdout RMSE]
1. quadratic: holdout RMSE=0.7056364626, train R^2=0.2690494754
2. linear: holdout RMSE=0.7056364626, train R^2=0.2690494754
3. exponential_growth: holdout RMSE=0.7446004630, train R^2=0.2556944336
4. shifted_quadratic: holdout RMSE=0.7468036954, train R^2=0.2540677998
======================================================================

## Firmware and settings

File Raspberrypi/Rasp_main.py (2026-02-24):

#!/usr/bin/env python3
"""
Raspberrypi Agent - Complete with Manual Control + Scan + Exposure Control
- ESP32 serial communication (Pan/Tilt)
- Manual control (move, LED, laser)
- Preview streaming
- Snap capture (Exposure control supported)
- IR-CUT control
- Grid Scan (Boustrophedon pattern)
Modified: 2026-02-12
- Added exposure control (shutter_speed, analogue_gain) to snap command
"""
import socket, struct, io, time, json, threading, glob
from picamera2 import Picamera2
import RPi.GPIO as GPIO
import serial

# ==================== GPIO 설정 ====================
IR_CUT_PIN = 17  # BCM 17번
LASER_PIN = 23   # BCM 23번

# ==================== 서버 설정 ====================
SERVER_OPTIONS = {
    "1": ("192.168.0.9", "711a"),
    "2": ("172.30.1.42", "602a"),
    "3": ("10.190.176.118", "hotspot")
}

def select_server():
    print("\n" + "="*50)
    print("서버 선택")
    print("="*50)
    for key, (ip, name) in SERVER_OPTIONS.items():
        print(f"  [{key}] {name:10s} → {ip}")
    print("="*50)
    
    while True:
        choice = input("서버 번호 (1/2/3) [기본: 2]: ").strip()
        if not choice: choice = "2"
        if choice in SERVER_OPTIONS:
            ip, name = SERVER_OPTIONS[choice]
            print(f"✓ 선택: {name} ({ip})\n")
            return ip

SERVER_HOST = select_server()
CTRL_PORT = 7500
IMG_PORT = 7501
BAUD = 115200

# ==================== 시리얼 (ESP32) ====================
def open_serial():
    """ESP32 시리얼 연결"""
    cands = ['/dev/ttyUSB0', '/dev/ttyUSB1', '/dev/ttyAMA0', '/dev/ttyS0'] + glob.glob('/dev/ttyUSB*')
    last_err = None
    for dev in cands:
        try:
            s = serial.Serial(dev, BAUD, timeout=0.2)
            print(f"[SERIAL] 연결: {dev}")
            return s
        except Exception as e:
            last_err = e
    raise RuntimeError(f"시리얼 연결 실패: {last_err}")

ser = open_serial()

def send_to_slave(obj: dict):
    """ESP32로 JSON 명령 전송"""
    ser.write((json.dumps(obj) + "\n").encode())
    ser.flush()

# ==================== 전역 변수 ====================
picam = None
preview_stop = threading.Event()
preview_thread = None
scan_stop = threading.Event()
scan_thread = None

# ==================== 이미지 전송 ====================
def push_image(sock: socket.socket, name: str, data: bytes):
    header = struct.pack("<H", len(name.encode())) + name.encode() + struct.pack("<I", len(data))
    sock.sendall(header)
    sock.sendall(data)

# ==================== Scan 유틸리티 ====================
def generate_boustrophedon_grid(pan_min, pan_max, pan_step, 
                                 tilt_min, tilt_max, tilt_step):
    """Boustrophedon 패턴 (뱀 모양) 그리드 생성"""
    grid = []
    tilt_values = list(range(tilt_min, tilt_max + 1, tilt_step))
    for tilt_idx, tilt in enumerate(tilt_values):
        pan_values = list(range(pan_min, pan_max + 1, pan_step))
        if tilt_idx % 2 == 1:
            pan_values.reverse()
        for pan in pan_values:
            grid.append((pan, tilt))
    return grid

# ==================== Scan Worker ====================
def scan_worker(cmd, ctrl_sock, img_sock):
    """Grid scan worker"""
    global picam
    
    try:
        # 파라미터 추출
        pan_min = int(cmd["pan_min"])
        pan_max = int(cmd["pan_max"])
        pan_step = int(cmd["pan_step"])
        tilt_min = int(cmd["tilt_min"])
        tilt_max = int(cmd["tilt_max"])
        tilt_step = int(cmd["tilt_step"])
        
        speed = int(cmd["speed"])
        acc = float(cmd["acc"])
        settle = float(cmd["settle"])
        led_settle = float(cmd.get("led_settle", 0.4))
        
        width = int(cmd["width"])
        height = int(cmd["height"])
        quality = int(cmd["quality"])
        session = cmd["session"]
        
        print(f"[SCAN] 시작: Pan[{pan_min}~{pan_max}:{pan_step}], Tilt[{tilt_min}~{tilt_max}:{tilt_step}]")
        
        # Grid 생성
        grid = generate_boustrophedon_grid(
            pan_min, pan_max, pan_step,
            tilt_min, tilt_max, tilt_step
        )
        total = len(grid)
        
        # Start 이벤트 전송
        ctrl_sock.sendall((json.dumps({
            "event": "start",
            "session": session,
            "total": total
        }) + "\n").encode())
        
        # 카메라 설정 (Scan은 Auto Exposure 사용 - YOLO 인식률 위해)
        picam.stop()
        config = picam.create_still_configuration(main={"size": (width, height)})
        picam.configure(config)
        picam.options["quality"] = quality
        picam.start()
        time.sleep(0.2)
        
        for i, (pan, tilt) in enumerate(grid):
            if scan_stop.is_set():
                break
            
            print(f"[SCAN] [{i+1}/{total}] Pan={pan}, Tilt={tilt}")
            
            # ① 이동
            send_to_slave({"T": 133, "X": float(pan), "Y": float(tilt), "SPD": speed, "ACC": acc})
            time.sleep(settle)
            
            # ② LED ON
            send_to_slave({"T": 132, "IO4": 255, "IO5": 255})
            time.sleep(led_settle)
            
            # ③ 촬영 (ON)
            bio = io.BytesIO()
            picam.capture_file(bio, format="jpeg")
            jpeg_data = bio.getvalue()
            bio.close()
            push_image(img_sock, f"{session}_t{tilt:+03d}_p{pan:+04d}_led_on.jpg", jpeg_data)
            
            # ④ LED OFF
            send_to_slave({"T": 132, "IO4": 0, "IO5": 0})
            time.sleep(led_settle)
            
            # ⑤ 촬영 (OFF)
            bio = io.BytesIO()
            picam.capture_file(bio, format="jpeg")
            jpeg_data = bio.getvalue()
            bio.close()
            name_off = f"{session}_t{tilt:+03d}_p{pan:+04d}_led_off.jpg"
            push_image(img_sock, name_off, jpeg_data)
            
            # ⑥ Progress
            ctrl_sock.sendall((json.dumps({
                "event": "progress",
                "done": i + 1,
                "total": total,
                "name": name_off
            }) + "\n").encode())
        
        ctrl_sock.sendall((json.dumps({"event": "done"}) + "\n").encode())
        print(f"[SCAN] 완료")
        
    except Exception as e:
        print(f"[SCAN] 오류: {e}")
        ctrl_sock.sendall((json.dumps({"event": "error", "message": str(e)}) + "\n").encode())
    
    finally:
        try:
            send_to_slave({"T": 132, "IO4": 0, "IO5": 0})
        except:
            pass

# ==================== 프리뷰 워커 ====================
# 1) preview_worker 시그니처/controls
def preview_worker(img_sock, w=640, h=480, fps=5, q=70, shutter_speed=None, analogue_gain=None):
    global picam
    try:
        print(f"[PREVIEW] 시작: {w}x{h} @ {fps}fps, Shutter={shutter_speed}, Gain={analogue_gain}")
        picam.stop()

        # Controls 설정 (Auto 복귀 보장)
        controls = {}
        manual = (shutter_speed is not None) or (analogue_gain is not None)

        if manual:
            controls["AeEnable"] = False
            if shutter_speed is not None:
                controls["ExposureTime"] = int(shutter_speed)
                controls["FrameDurationLimits"] = (int(shutter_speed) + 5000, 2000000)
            if analogue_gain is not None:
                controls["AnalogueGain"] = float(analogue_gain)
        else:
            controls["AeEnable"] = True



        config = picam.create_video_configuration(main={"size": (w, h)}, controls=controls)
        picam.configure(config)
        picam.options["quality"] = int(q)
        picam.start()
        time.sleep(0.1)
        
        interval = 1.0 / max(1, fps)
        
        while not preview_stop.is_set():
            bio = io.BytesIO()
            picam.capture_file(bio, format="jpeg")
            push_image(img_sock, f"_preview_{int(time.time()*1000)}.jpg", bio.getvalue())
            bio.close()
            time.sleep(interval)
            
    except Exception as e:
        print(f"[PREVIEW] 오류: {e}")
    finally:
        try:
            picam.stop()
        except:
            pass

# ==================== 스냅 캡처 (노출 제어 추가) ====================
def snap_capture(img_sock, w, h, q, name, shutter_speed=None, analogue_gain=None):
    """
    고해상도 스틸 이미지 캡처 (노출 제어 가능)
    shutter_speed: 노출 시간 (microseconds), None이면 Auto
    analogue_gain: 아날로그 게인 (1.0 ~ 16.0 등), None이면 Auto
    """
    global picam
    bio = None
    try:
        print(f"[SNAP] 캡처 중: {w}x{h}, quality={q}")
        if shutter_speed:
            print(f"       👉 노출 제어: Shutter={shutter_speed}µs, Gain={analogue_gain}")
        
        # 프리뷰 중지
        preview_stop.set()
        if preview_thread and preview_thread.is_alive():
            preview_thread.join(timeout=0.7)
        
        # Still 모드로 전환 + 노출 제어
        picam.stop()
        
        # Controls 설정 (Auto 복귀 보장)
        controls = {}
        manual = (shutter_speed is not None) or (analogue_gain is not None)
        if manual:
            controls["AeEnable"] = False
            if shutter_speed is not None:
                # 노출 시간 (µs)
                controls["ExposureTime"] = int(shutter_speed)
                min_duration = int(shutter_speed) + 5000  # 여유 5ms
                controls["FrameDurationLimits"] = (min_duration, 2000000)  # 최대 2초
            if analogue_gain is not None:
                # 아날로그 게인
                controls["AnalogueGain"] = float(analogue_gain)
        else:
            controls["AeEnable"] = True
            
        config = picam.create_still_configuration(main={"size": (w, h)}, controls=controls)
        picam.configure(config)
        picam.options["quality"] = int(q)
        picam.start()
        
        # 노출 안정화 대기 (수동 노출은 더 짧아도 됨)
        # 하지만 Auto일 경우를 대비해 넉넉히
        wait_time = 0.2 if manual else 0.5
        time.sleep(wait_time)
        
        # 캡처
        bio = io.BytesIO()
        picam.capture_file(bio, format="jpeg")
        jpeg_data = bio.getvalue()
        
        # 전송
        push_image(img_sock, name, jpeg_data)
        print(f"[SNAP] 완료: {name} ({len(jpeg_data)} bytes)")
        
    except Exception as e:
        print(f"[SNAP] 오류: {e}")
    
    finally:
        if bio: bio.close()
        try:
            picam.stop()
        except:
            pass

# ==================== 메인 ====================
def main():
    global picam, preview_thread, scan_thread
    
    # GPIO 초기화
    GPIO.setmode(GPIO.BCM)
    GPIO.setup(IR_CUT_PIN, GPIO.OUT, initial=GPIO.LOW)
    GPIO.setup(LASER_PIN, GPIO.OUT, initial=GPIO.LOW)
    print("[GPIO] 초기화 완료")
    
    # 카메라 초기화
    picam = Picamera2()
    print("✅ 카메라 준비 완료")
    
    # 서버 연결
    print(f"\n서버 연결: {SERVER_HOST}:{IMG_PORT}")
    while True:
        try:
            img_sock = socket.socket(socket.AF_INET, socket.SOCK_STREAM)
            img_sock.connect((SERVER_HOST, IMG_PORT))
            print("✅ IMG 소켓 연결!")
            break
        except Exception as e:
            time.sleep(1.0)
    
    print(f"제어 소켓 연결: {SERVER_HOST}:{CTRL_PORT}")
    while True:
        try:
            ctrl_sock = socket.socket(socket.AF_INET, socket.SOCK_STREAM)
            ctrl_sock.setsockopt(socket.IPPROTO_TCP, socket.TCP_NODELAY, 1)
            ctrl_sock.connect((SERVER_HOST, CTRL_PORT))
            print("✅ CTRL 소켓 연결!")
            break
        except Exception as e:
            time.sleep(1.0)
    
    print("\n" + "=" * 60)
    print("명령 대기 중...")
    print("=" * 60)
    
    # 명령 수신
    buf = b""
    try:
        while True:
            data = ctrl_sock.recv(4096)
            if not data: break
            buf += data
            
            while True:
                nl = buf.find(b"\n")
                if nl < 0: break
                line = buf[:nl].decode("utf-8", "ignore").strip()
                buf = buf[nl+1:]
                if not line: continue
                
                try:
                    cmd = json.loads(line)
                except:
                    continue
                
                c = cmd.get("cmd")
                
                if c == "preview":
                    enable = cmd.get("enable", True)
                    if enable:
                        preview_stop.set()
                        if preview_thread and preview_thread.is_alive():
                            preview_thread.join(timeout=0.5)
                        
                        preview_stop.clear()
                        w = int(cmd.get("width", 640))
                        h = int(cmd.get("height", 480))
                        fps = int(cmd.get("fps", 5))
                        q = int(cmd.get("quality", 70))
                        shutter = cmd.get("shutter_speed")
                        gain = cmd.get("analogue_gain")

                        preview_thread = threading.Thread(
                            target=preview_worker,
                            args=(img_sock, w, h, fps, q, shutter, gain),
                            daemon=True
                        )
                        preview_thread.start()
                        print(f"[CMD] 프리뷰 시작 (Shutter={shutter}, Gain={gain})")

                    else:
                        preview_stop.set()
                        if preview_thread:
                            preview_thread.join(timeout=0.7)
                        print("[CMD] 프리뷰 중지")
                
                elif c == "snap":
                    w = int(cmd.get("width", 2592))
                    h = int(cmd.get("height", 1944))
                    q = int(cmd.get("quality", 95))
                    name = cmd.get("save", "snap.jpg")
                    
                    # ⭐ 노출 제어 파라미터 추가
                    shutter = cmd.get("shutter_speed") # None or int (µs)
                    gain = cmd.get("analogue_gain")    # None or float
                    
                    threading.Thread(
                        target=snap_capture,
                        args=(img_sock, w, h, q, name, shutter, gain),
                        daemon=True
                    ).start()
                    print(f"[CMD] Snap 요청 {'(Exposure Controlled)' if shutter else ''}")
                
                elif c == "scan_run":
                    scan_stop.set()
                    if scan_thread and scan_thread.is_alive():
                        scan_thread.join(timeout=1.0)
                    scan_stop.clear()
                    scan_thread = threading.Thread(
                        target=scan_worker,
                        args=(cmd, ctrl_sock, img_sock),
                        daemon=True
                    )
                    scan_thread.start()
                    print("[CMD] Scan 시작")
                
                elif c == "scan_stop":
                    scan_stop.set()
                    if scan_thread:
                        scan_thread.join(timeout=1.0)
                    print("[CMD] Scan 중지")
                
                elif c == "move":
                    pan = float(cmd.get("pan", 0.0))
                    tilt = float(cmd.get("tilt", 0.0))
                    speed = int(cmd.get("speed", 100))
                    acc = float(cmd.get("acc", 1.0))
                    send_to_slave({"T": 133, "X": pan, "Y": tilt, "SPD": speed, "ACC": acc})
                
                elif c == "led":
                    val = int(cmd.get("value", 0))
                    send_to_slave({"T": 132, "IO4": val, "IO5": val})
                
                elif c == "laser":
                    val = int(cmd.get("value", 0))
                    GPIO.output(LASER_PIN, GPIO.HIGH if val else GPIO.LOW)
                
                elif c == "ir_cut":
                    mode = cmd.get("mode", "day")
                    GPIO.output(IR_CUT_PIN, GPIO.LOW if mode == "day" else GPIO.HIGH)
    
    except KeyboardInterrupt:
        print("\n[EXIT] 종료 중...")
    finally:
        preview_stop.set()
        scan_stop.set()
        GPIO.cleanup()
        try: ctrl_sock.close()
        except: pass
        try: img_sock.close()
        except: pass

if __name__ == "__main__":
    main()

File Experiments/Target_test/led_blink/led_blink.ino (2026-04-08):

#include <Arduino.h>

const uint8_t PIN_LED_R = 2;
const uint8_t PIN_LED_B = 3;
const uint8_t PIN_LED_G = 4;

// 1초 간격 테스트용, 필요시 10000ms로 바꾸면 10초 간격
const unsigned long STATE_INTERVAL_MS = 10000UL;

unsigned long g_started_ms = 0;
unsigned long g_last_step_ms = 0;
int g_stage = 0;

void setBatteryLedBits(int stage) {
  if (stage < 0) stage = 0;
  if (stage > 7) stage = 7;
  int ledValue = 7 - stage;

  digitalWrite(PIN_LED_R, (ledValue & 0b100) ? HIGH : LOW);
  digitalWrite(PIN_LED_B, (ledValue & 0b010) ? HIGH : LOW);
  digitalWrite(PIN_LED_G, (ledValue & 0b001) ? HIGH : LOW);
}

const char* stageToBits(int stage) {
  switch (stage) {
    case 0: return "111";
    case 1: return "110";
    case 2: return "101";
    case 3: return "100";
    case 4: return "011";
    case 5: return "010";
    case 6: return "001";
    default: return "000";
  }
}

void printState(int stage) {
  unsigned long elapsed_s = (millis() - g_started_ms) / 1000UL;
  Serial.print("t=");
  Serial.print(elapsed_s);
  Serial.print("s stage=");
  Serial.print(stage);
  Serial.print(" bits=");
  Serial.println(stageToBits(stage));
}

void setup() {
  pinMode(PIN_LED_R, OUTPUT);
  pinMode(PIN_LED_B, OUTPUT);
  pinMode(PIN_LED_G, OUTPUT);

  Serial.begin(9600);
  g_started_ms = millis();
  g_last_step_ms = g_started_ms;
  g_stage = 0;

  setBatteryLedBits(g_stage);
  printState(g_stage);
}

void loop() {
  unsigned long now = millis();
  if (now - g_last_step_ms < STATE_INTERVAL_MS) {
    return;
  }

  g_last_step_ms = now;
  g_stage = (g_stage + 1) % 8;
  setBatteryLedBits(g_stage);
  printState(g_stage);
}

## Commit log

2026-01-05 feat(rx): 배터리 전압 모니터링 추가 - A0 핀 기반 전압 측정을 위한 Battery_test.ino 추가 - 2배 전압 분배 회로 계산 지원 - 1초마다 전압을 시리얼로 출력 docs(readme): 배터리 테스트 펌웨어 문서화 - Arduino 펌웨어 문서에 Battery_test 섹션 추가 - 디렉토리 구조 다이어그램 업데이트
2026-01-06 refactor(INA219): 출력을 CSV에서 한글 텍스트로 변경
    - 가독성 높은 형식으로 전압/전류 출력
    - 전력 측정 제거
    - README 업데이트
2026-01-07 fix: 라즈베리파이 연결 IP 주소 수정
    - Rasp_main.py의 서버 IP 주소 변경
    [Rasp_main.py]
2026-01-08 refactor(mot): mot_scan_test.py를 MOT.py 알고리즘으로 업데이트 HSV+Grayscale 특징, Diff 마스크, 11x11 격자, 300px ROI, 0.35 threshold 적용
2026-01-08 feat(mot): LED OFF 특징 추출 테스트 버전 추가 - mot_scan_test_off.py: 배경 패턴으로 추적 실험
2026-01-08 feat(mot): Track 병합 후처리 및 헝가리안 알고리즘 버전 추가 - Track 병합: 추적 완료 후 유사한 track ID 자동 병합 (대표 샘플 3개 비교) - 병합 로그: 모든 비교 유사도 값(개별값 포함) 상세 기록 - 헝가리안 알고리즘: mot_scan_test_hungarian.py 추가 (전역 최적 매칭) - 파일 파싱 수정: .ud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
2026-01-08 feat(mot): Track 병합 후처리 및 헝가리안 알고리즘 추가 주요 변경사항: - 적응형 샘플링: 1-2개 검출 Track도 병합 가능 (큰 Track 크기에 맞춰 샘플링) - 병합 로그 개선: Track 크기, 샘플 수, 개별 유사도 값 모두 기록 - 헝가리안 알고리즘: mot_scan_test_hungarian.py 추가 (전역 최적 매칭) -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
2026-01-08 refactor: MOT 트랙 병합 알고리즘을 공간 기반 샘플링으로 개선 - 적응형 샘플링 대신 Pan/Tilt 라인 기반 비교 적용 - 같은 Pan 또는 Tilt 라인에서만 유사도 계산 - merge_threshold를 0.3에서 0.4로 상향 조정
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2026-01-13 feat: 최적화된 헝가리안 MOT 알고리즘 최종 구현 mot_scan_test_hungarian_final.py 추가: - 양방향 대각선을 각 방향당 1개로 최적화 - n-2 프레임 + 최적화된 대각선 후보 검색 - 헝가리안 알고리즘 기반 글로벌 최적 매칭 README 업데이트: - 최종 알고리즘 상세 스펙 문서화 - MOT 실험 버전 재분류
2026-01-13 docs: 저작권 준수를 위해 논문 PDF를 메타데이터 파일로 대체
    - Docs/Publications.md 추가 (논문 제목, 학회, 요약 포함)
    - 원본 PDF 파일 삭제하여 저작권 문제 방지
2026-01-14 Refactor: MOT 알고리즘을 Hungarian 방식으로 교체 - Greedy 매칭에서 Hungarian 알고리즘으로 변경 (최적 매칭) - 양방향 대각선 후보 최적화 (1개씩 수집) - merge_similar_tracks() 메서드 추가 - Threshold 통일 (0.5)
2026-01-17 fix: MOT 알고리즘 매칭 임계값을 주석에 맞게 수정
    Com_test/MOT.py와 Experiments/mot_scan_test_hungarian_final.py의
    임계값을 주석에 명시된 값으로 변경:
    - Direct frame matching: 0.5 → 0.3
    - Skip frame matching: 0.5 → 0.35
    더 엄격한 매칭으로 초기 track 분리를 강화하여
    merge_similar_tracks() 단계에서 후처리 병합 수행
2026-01-20 docs: Add Future Works section to README
    - 적외선 레이저(850nm, 1W) 및 IR cut camera 교체 계획 추가
    - 전체시스템 통합 및 RX 효율 설계 항목 포함
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2026-01-23 feat: IR 필터 제어 및 카메라 스트리밍 테스트 추가
    - GPIO 기반 IR 필터 On/Off 제어
    - Flask 웹 서버로 실시간 카메라 스트리밍
    - Day/Night 모드 전환 UI 구현
    - 레이저 번짐(Blooming) 현상 테스트용
2026-01-26 refactor: 3D 프린터 관련 파일을 전용 디렉토리로 재구성
    - RX 디렉토리에서 Target 관련 3D 프린터 파일 이동
    - TX_mount 3D 프린터 파일 추가
    - 모든 3D 프린터 파일(.3mf, .gcode.3mf, .stl)을 3D_printer/ 디렉토리로 통합 관리
    [TX_mount.3mf, TX_mount.gcode.3mf, TX_mount.stl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]
2026-01-27 refactor(experiments): Experiments 폴더를 기능별 4개 카테고리로 재구성 27개의 실험 파일을 기능별로 분류하여 관리 편의성 향상: - MOT_test/: 다중 객체 추적 알고리즘 (8개) - Detection_test/: YOLO 객체 탐지 (5개) - Filter_test/: Diff 이미지 필터링 (12개) - Hardwa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
2026-01-28 MOT 알고리즘 개선: 중복 후보 제거 및 3가지 비교 방식 구현 1. hungarian_final: 중복 대각선 후보 제거 (Type 3, 5) - 최종 5개 프레임 타입만 사용 - Threshold 0.5로 통일
    2. comparison_test: 3가지 비교 버전으로 재작성
    - Grid vs NoGrid vs Temporal 비교
    - 스킴별 폴더 분리 저장
2026-01-28 refactor: 중복 후보 제거 및 3가지 MOT 비교 방식 구현 - hungarian_final: Type 3(prev_diagonal), Type 5(skip_tilt) 제거로 중복 방지 - 최종 5개 프레임 타입만 사용 (prev_pan/tilt, skip_pan, diagonal_increase/decrease) - Threshold 0.5로 통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
2026-01-28 refactor(mot): 중복 후보 제거, 4가지 비교 방식 구현 및 Grid 설정 개선 - hungarian_final: Type 3/5 제거, threshold 0.5 통일, GRID_SIZE 상수 추가 - comparison_test: 4가지 비교 (Grid/NoGrid × Spatial/Temporal), track merge 적용 - docs: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
2026-01-28 feat: IR-CUT 카메라 GUI 클라이언트 추가 - 이미지 수신 및 프리뷰 표시 구현 - 프리뷰 활성화/비활성화 제어 추가 - IR-CUT Day/Night 모드 토글 버튼 추가 - 서버 제어/이미지 채널 연결
2026-01-28 feat: IR-CUT 카메라 에이전트 및 프리뷰 스트리밍 추가 - Picamera2 기반 카메라 제어 구현 - 연속 프리뷰 스트리밍 기능 추가 (640x480) - GPIO 17을 통한 IR-CUT 필터 제어 - Day/Night 모드 전환 지원 - 서버 제어/이미지 소켓 연결
2026-01-28 refactor: Com 클라이언트 모듈화 - 네트워크 클라이언트를 network.py로 분리 (GuiCtrlClient, GuiImgClient) - UI 컴포넌트를 ui_components.py로 분리 (PreviewFrame, ControlPanel) - Com_main.py를 앱 로직에만 집중하도록 간소화 - Com_test와 구조 일치
2026-01-30 feat: 탭 UI 및 스냅 캡처 기능 추가 - network.py, ui_components.py, Com_main.py로 모듈화 - 탭 인터페이스 추가 (Scan, Manual/LED, Preview & Settings) - 스냅 캡처 구현 (5MP + 3MP 순차 촬영) - captures/ 폴더에 이미지 자동 저장 - IR-CUT Day/Night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
2026-01-30 feat: 탭 UI 및 스냅/수동 제어 기능 추가 Com 클라이언트 모듈화: - network.py, ui_components.py, Com_main.py로 분리 - network.py: GuiCtrlClient, GuiImgClient (이미지 이름 지원) - ui_components.py: PreviewFrame, ScanTab, ManualTab, 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
2026-01-30 feat: ESP32 시리얼 통신을 통한 수동 제어 추가 수동 제어 기능: - ESP32 시리얼 통신 (USB 포트 자동 감지) - Pan/Tilt 이동 명령 (T:133, X/Y/SPD/ACC) - LED 제어 명령 (T:132, IO4/IO5) - 레이저 토글 (GPIO 15) 명령 핸들러: - "move": Pan/Tilt 위치 제어 - "led":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
    [test.py]
2026-01-30 refactor: Manual과 Preview 탭을 Test & Settings로 통합
    UI 간소화:
    - 3개 탭 → 2개 탭으로 축소 (Scan, Test & Settings)
    - ManualTab과 PreviewTab을 TestSettingsTab으로 통합
    Test & Settings 탭 구성:
    - 🎮 Pan/Tilt 제어 (슬라이더 + 숫자 입력)
    - 💡 LED & 레이저 (밝기 제어 + 레이저 토글)
    - 📹 프리뷰 설정 (라이브 프리뷰 + 해상도/fps/품질)
    - 📸 캡처 (Snap 5MP+3MP 버튼)
    - 🌓 IR-CUT 제어 (Day/Night 모드 버튼)
    ui_components.py:
    - ManualTab과 PreviewTab 클래스 병합
    - 아이콘 포함 섹션 헤더 추가
    - 섹션 간 구분선 추가
    - 버튼 스타일 개선 (컬러 버튼)
    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
2026-01-31 docs: README 디렉토리 구조를 실제 프로젝트 계층과 일치하도록 수정
    - Com_650nm/ 폴더 구조 명확화 (실제 메인 코드 위치)
    - 루트 Com/ 폴더를 간소화된 테스트 버전으로 재정의
    - PC Client 섹션 경로 수정 (Com/ → Com_650nm/Com/)
    - 누락된 파일 문서화 추가:
    - Raspberrypi/test.py, Server/test.py
    - RX/Arduino/Mini_LED_test/
    - Experiments/MOT_test/mot_comparison_test.py
    - 3D_printer/, testfile.py
    - Raspberry Pi Agent 섹션에 두 위치의 Rasp_main.py 설명 추가
    - 디렉토리 구조 섹션 완전 재작성 (실제 파일 계층 반영)
    - MOT_test 파일 개수 수정 (8개 → 9개)
2026-02-01 docs: README에 Publications 섹션 추가
    - 관련 학회 논문 및 발표자료 섹션 추가
    - KICS 2025/2026 논문 2편 링크 포함
    - Docs/Publications.md 참조 링크 추가
2026-02-03 refactor(test.py): Preview/Snap 함수 단순화 - preview_worker: 복잡한 에러 복구 로직 제거 - frame_count, error_count 카운터 제거 - try-finally 블록 단순화 - 주기적 로그 제거 - snap_capture: finally 블록 제거 - BytesIO cleanup 로직 제거 - 카메라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
    [test.py]
2026-02-03 feat: UI 개선 및 하드웨어 초기화 추가 - Resolution Combobox 추가 (Scan/Preview 탭) - VGA, 1.3MP, Full HD, 5MP 드롭다운 선택 - 선택 시 width/height 자동 설정 - Snap 캡처가 Preview 해상도 사용하도록 변경 - 앱 시작 시 하드웨어 전체 초기화 로직 추가 - Preview O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
2026-02-03 fix(rasp): 스캔 타이밍 시퀀스를 기존 로직과 일치시킴 - 스캔 촬영 시퀀스를 기존 Rasp_main.py와 동일하게 복원: 이동 -> Settle -> LED ON -> LED Settle -> 촬영 -> LED OFF -> LED Settle -> 촬영 - 카메라 흔들림 방지를 위해 타이밍 파라미터 일관성 확보 - 모터 안정화(0.1초)와 LE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
    [test.py]
2026-02-03 fix(com): 안정적인 스캔을 위한 기본 파라미터 최적화 - UI 기본 스캔 설정을 검증된 값으로 업데이트: - Settle 시간 증가: 0.1초 -> 0.4초 (흔들림 제거) - Speed: 0 (최대 속도) - Accel: 0.0 (최대 가속) - Com_650nm 레거시 설정과 기본값 통일
2026-02-04 fix : ppt 내용 교수님 피드백 바탕으로 수정 1. 마침표 지우기 [x] 2. ROI 써놓기 , 명사말고 동사 -> ex ROI 생성 이런느낌... [x] 3. HSV 의미 [x] 4. 헝가리안 알고리즘 대략 설명 [x] 5. ID Assigment 그 그그그 쓰레시 홀드값 설명하기 [x] 6. 성능평가 값 설명할때 그 물리적 의미 [x] --- p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
2026-02-05 feat : tesfile.py 그래프 뽑기용 코드 ppt 결과만 내용 수정하면 됨
2026-02-05 fix : 동계 마무리
2026-02-07 fix: Com GUI에서 스캔 progress bar 업데이트 기능 추가
    - GuiCtrlClient에 이벤트 수신 루프 구현
    - event_queue를 통해 start/progress/done/error 이벤트 처리
    - _handle_event 메서드로 실시간 progress bar 업데이트
    - 스캔 진행 상황 UI 표시 개선 (0/100 → 100/100)
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2026-02-09 refactor(Com): Com_650nm 모듈화 구조 적용 (Phase 1)
    모듈 분리:
    - event_handlers.py 추가 (이벤트 처리 믹스인)
    - app_helpers.py 추가 (헬퍼 메서드 믹스인)
    - network.py 리팩토링 (전역 ui_q + 자동 재연결)
    - Com_main.py 리팩토링 (믹스인 패턴 적용)
    버그 수정:
    - 이미지 중복 저장 문제 해결
    - 'no agent connected' 에러 메시지 제거
    향후 기능 확장을 위한 구조 준비 완료
2026-02-09 refactor(Com): 모듈화 및 YOLO 스캔 알고리즘 구현 (Phase 1-2)
    Phase 1 - 코드 모듈화:
    - network.py 추가: 전역 ui_q, 자동 재연결 (3초 재시도)
    - event_handlers.py 추가: 이벤트 처리 믹스인
    - app_helpers.py 추가: 헬퍼 메서드 믹스인
    - Com_main.py 리팩토링: 믹스인 패턴 적용
    - 이미지 중복 저장 문제 수정
    Phase 2 - YOLO 스캔:
    - yolo_utils.py 추가: 타일 방식 추론 (2x3), NMS, 모델 캐싱
    - scan_controller.py 업그레이드: Worker Thread, LED ON/OFF 쌍 매칭
    - YOLO weights 입력 추가 (기본값: ../yolov11m_diff.pt)
    - YOLOProcessor 통합
    - CSV 저장: pan, tilt, cx, c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
2026-02-09 refactor(Rasp): GPIO 수정 15->23
    기존 GPIO 15 가 항상 HIGH 출력됨에 따라 레이저 출력 조절을 위해 GPIO 23으로 수정
    [test.py]
2026-02-10 fix: Preview-Scan 충돌 해결 및 MOT 알고리즘 hungarian_final 정렬 Preview-Scan 충돌 해결: - Scan 시작 시 Preview 스트림 자동 중지 - Scan 이미지는 Preview에 계속 표시 - preview_active 상태 추적 추가 MOT 파라미터 hungarian_final 정렬: - Threshold: 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
2026-02-10 fix: IR-CUT UI 개선 및 MOT 파라미터 hungarian_final 정렬 IR-CUT 개선: - 버튼 라벨: Day/Night → Normal/IR Mode (직관적) - 명령 매핑: 하드웨어 동작 반대로 역매핑 - Normal 버튼 → "night" 명령 (가시광선) - IR Mode 버튼 → "day" 명령 (적외선, 레이저 보임) MOT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
2026-02-10 fix: MOT 로깅 구현 및 실시간-테스트 스크립트 동기화
    MOT 로그 저장:
    - Com/mot.py에 save_similarity_log 추가 (테스트 스크립트와 동일 포맷)
    - scan_controller에서 세션 종료 시 similarity_log_live.txt 자동 저장
    - event_handlers에서 scan done 시 stop_scan 자동 호출
    MOT 파라미터 동기화:
    - Matching threshold: 0.5 → 0.4
    - _find_prev_candidates: 5후보 공간 검색으로 통일
    - add_detections: comparisons 상세 로그 기록 추가
    테스트 스크립트 정렬:
    - OFF 이미지 사용 (실시간 코드와 동일)
    - MOT_CONF_THRESHOLD >= 0.50 필터링 추가
    - Boustrophedon 정렬 동적 Step 지원
    UI 버그 수정:
    - scan_btn_st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
2026-02-12 feat : difff_color_redinput.py Laser 중심찾을때 Red filter 확인할려고 만듦 슬라이더 조절시 이미지에서 Red 만 더해짐
2026-02-12 feat : check_laser_pos.py - 레이저 중심좌표 고정 확인 코드 - 이미지 여러장 입력해서 마우스 찍으면 중심좌표 남음 - X 1310~1317 - Y 720~830 나옴
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2026-02-12 feat(Rast) : test.py 에 노출시간 조절하는 코드 수정 (captures 시 에만 우선 조절)
    [test.py]
2026-02-12 fix: 조준 로직 오류 수정 및 노출 제어 최적화 ComApp 초기화 시 pointing_gains 누락으로 인한 충돌 해결 pointing_handler.py 헬퍼 함수 복구 (
    find_object_center
    ,
    find_laser_center
    )
    정밀 조준 스텝별 수동 노출(Manual Exposure) 적용
    LED 탐지: 100ms (100000µs)
    레이저 탐지: 500µs
    레이저 검출 ROI 축소(300px) 및 Threshold(40) 조정으로 성능 개선
2026-02-13 fix : pointing_handelr.py - 기존 오브젝트 인식하는 방식 Scan 과 동일하게 수정
2026-02-20 feat(RX) : 8x8 cm^2 RX 용 3mf
    [18_8test.gcode.3mf, 8_8.gcode.3mf, 8_8test.3mf]
2026-02-21 fix(pointing) : 기존 650nm 에 맞게 pointing algorithm fix
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2026-02-23 fix (pointing) : pointing 시 debug 이미지에 pan,tilt 나오게 수정
2026-02-23 feat(3d printer) : pointing align 할때 retrofilm 이 너무 잘 반사되서 인식 오류가 너무 생겨서 구조를 수정 재귀반사필름을 5.5cm 위로 더올림
    [8_8_align.3mf, 8_8_align.gcode.3mf]
2026-02-24 feat(settings.json) : vscode 로 실행시 필요한 settings json 파일인듯. server, Com_main 으로 생성됨
2026-02-24 fix(preview) : 1. Scan, Captures 이후 preview 상태 받아서 기존에 preview 켜져있으면 Scan Stop/End , Captures 이후 preview on/off
    2. TCP 프레임 부분 수신 안정화
    [test.py]
2026-02-24 refactor(Scan) : 중간에 Stop 시 바로 Stop 안되고 tail 처리시간 만들어서 이미지 누락 방지
2026-02-24 refactor (preview) : laser pointing 방식 수정에 따른 십자선 제거
2026-02-24 refactor(YOLO) : yolo_processor 중복 생성에 따른 메모리 낭비 수정 1. shared_yolo = YOLOProcessor() 단일 생성 2. self.yolo - shared_yolo 3. self.yolo_processor = shared_yolo 4. 두번째 yolo_processor 삭제
2026-02-24 fix(Rasp) : IP 수정
    [test.py]
2026-02-24 refactor(preview) : preview 큐에 계속 넣으면 메모리 위험해서 수정 1. ui_q 에 preview 계속 넣지 않고, 단일슬롯 으로 저장. 2. _poll()에서 매 주기 최신 preview 1장만 꺼내서 표시
2026-02-24 refactor(pointing) : pointing 종료시에도 preview 상태 받고 종료/끝 시에도 prview on/off
    1. 시작시 prview 상태 저장
    2. aiming 종료.중단 후 복구 헬퍼 추가
    3. 조준 스레드 에서 항상 복구 실행
    4. Stop 시 snap 대기 즉시 해제
2026-02-24 refactor(MOT) : 1. 최종 Track수 병합 Track 으로 수정
2026-02-24 refactor (Preview) : Camera Gain 이랑 Shutter 값 preview 에도 적용할수있게 수정
2026-02-24 refactor (Rasp/Preview) : Camera Gain 이랑 Shutter 값 preview 에도 적용할수있게 수정
    [test.py]
2026-02-24 fix (pointing) : Target 위치 수정 9 -> 12.25
2026-02-24 refactor (Scan) : Hard ware 값 수정 tilt_step : 10 -> 5 led_settle : 0.4->0.2 settle : 0.4 -> 0.25
2026-02-24 refactor (Scan) : 602Eh test env 에서 편한값 초기 hard setting, step 은 5로 유지 pan -30~0 , step 5 tilt -10~10 , step 5
2026-02-24 fix (Rast/pointing) : snap capture 의 manual 미정의 오류 해결
    [test.py]
2026-02-24 refactor (pointing) : 초기위치 하여 버튼 생성 했을때, 버튼누르면 바로 pointing 되는거에서 초기위치, pointnig 버튼추가
2026-02-24 refactor (pointing) : 수렴 임계값 변경 x : 7 -> 7 y : 7 -> 25
    수렴시 각 ID 버튼누르면 수렴값으로 pan, tilt 이동
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2026-02-24 feat (Scheduling) : Roundrobin 구현 1. Scan -> pointing -> 10초씩 Roundrobin align 으로 일단 설정
2026-02-26 refactor(led filter) : 1. 이미지 폴더 선택후 전체 이미지 순회 2. 트랙바로 RGB 필터 임게값 실시간 조절 3. 예측결과 + 픽셀 카운트 표시 4. RGB 마스크 3개 동시 표시 5. n/d 다음 p/a 이전 s 파라미터 저장 q 종료
2026-02-27 feat(RX/arduino) : Battery 로 arduino 구동 테스트겸 LED 8번 pin 꽂으면 항상 ON
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2026-02-28 test(led_rgb_tuner.py) : test set 에 따라 최적값 찾아 수정
    r_min : 60
    g_min : 60
    b_min : 60
    rg_min : 10
    rb_min : 40
    gr_min : 10
    gb_min : 10
    br_min : 40
    bg_min : 40
    min_pixels : 0
2026-02-28 feat(hw): add RX battery logger firmware and serial dump helper script RX/Arduino/RX/RX.ino 신규: EEPROM 링버퍼 배터리 로깅 + CSV dump testfile.py 변경: 시리얼 명령으로 battery_log.csv 수집 도구로 전환
2026-02-28 fix(pointing): quantize pan/tilt consistently across compute, move, start, and final update Com/pointing_handler.py _quantize_deg, _quantize_pan_tilt 추가 계산/이동/시작/최종저장 시 pan/tilt 정수화 일관 적용 fix(pointin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
2026-02-28 feat(scheduling): integrate adaptive convergence, LED probing, and overlay telemetry Com/Com_main.py RoundRobin dwell 기본 20s ID별 adaptive 수렴 플로우 반영 shoot 중 주기적 LED probe(단일 ROI) + overlay에 timer/ID/L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
2026-02-28 feat(ui): fix aiming mode to adaptive and add scheduling battery-check interval Com/ui_components.py aiming mode 콤보 제거, adaptive 고정 Scheduling에 Shoot Timer, Battery Check 입력 필드 추가
2026-02-28 fix(event): notify blocking snap waiter on image saved events Com/event_handlers.py 저장 이벤트 수신 시 scheduling blocking-snap 대기자에게 프레임 전달
2026-02-28 feat(led): add shared LED filter module for ROI-based RGB classification Com/led_filter.py 신규 RGB 임계값 기반 마스크, ROI 확장(target 위 1/3), 단일프레임/ON-OFF 분류 함수 추가
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2026-03-03 chore(Publications.md) : 내용 수정 - 작성 논문 수정 - 참고 논문 추가
2026-03-03 Docs(3D_printer) : 3D_printer tx,rx 정리해서 분리 - RX (12_12_RX) : 기존 12.5cm x 12.5cm solarcell 기준 RX 파일 정리 - RX (8_8_RX) : 기존 8cm x 8cm solarcell 기준 RX 파일 정리 - TX (TX) : TXmount 파일 정리
    [18_8test.gcode.3mf, 8_8.gcode.3mf, 8_8_align.3mf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]
2026-03-03 chore(README.md) : README system model 완성에 맞게 수정
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2026-03-04 chore(test.py) : 기존 TX.ino 에 맞게 x,y 축 수정 - 'time_s' : x - 'vbat_mV' : y
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2026-03-05 chore(gitignore) : captures update 수정 - captures/ 넣어서 결과물은 확실히 안올라가게 수정
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2026-03-12 chore(Battery_test.ino) : BAUD 수정 - 19200 -> 9600
    [Battery_test.ino]
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2026-03-14 feat(RX.ino) : 테스트결과 470K + 100K 방식으로 전압낮춰서 계산하는거로 수정 - analogReference(INTERNAL) 후 5.7배 곱하기
2026-03-14 chore(Battery_test) : BAUD 9600으로통일하고 둘다 5.7 방식 으로 수정
    [Battery_test.ino, Battery_test_5.ino]
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2026-03-16 chore(testfile.py) : csv 이름 수정 - battery_log_n.csv -> n.csv
2026-03-16 chore(test.py) : IP 수정 - 1.42 -> 1.13 (602a)
    [test.py]
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2026-03-16 chore(RX.ino) : Battery 비율 수정 - 3300 -> 3000
2026-03-16 chore(mot.py) : tr 수정 - 0.35->0.4
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2026-03-18 chore(pointing_tab) : pointing 진행시 preview 수정 - phase 3 debug 추가
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2026-03-18 fix(pointing_workflow) : phase3 비활성화
2026-03-20 chore(RX.ino) : 저항 수정에 따른 값수정 - 470K + 100K -> 100K + 20K - 5.7 -> 6
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2026-03-26 chore(mot.py) : tr 수정 - 0.4 -> 0.41
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2026-03-28 feat(window.py) : pointing 수정 및 roundrobin frame 수정 - pointing 시 phase 2/3 에서 객체 화면 중심 roi 500x500 에서 미검출시 다시 검출 시도 - phase 3에서 +1 내림차순으로 계산 - round robin 시 frame 시간의 합이 total 합의 되도록 수정
2026-03-28 feat(pointing_tap.py) : pointing 수정 및 roundrobin frame 수정 - pointing 시 phase 2/3 에서 객체 화면 중심 roi 500x500 에서 미검출시 다시 검출 시도 - phase 3에서 +1 내림차순으로 계산 - round robin 시 frame 시간의 합이 total 합의 되도록 수정
2026-03-28 feat(pointing_workflow.py) : pointing 수정 및 roundrobin frame 수정 - pointing 시 phase 2/3 에서 객체 화면 중심 roi 500x500 에서 미검출시 다시 검출 시도 - phase 3에서 +1 내림차순으로 계산 - round robin 시 frame 시간의 합이 total 합의 되도록 수정
2026-03-28 fix(window.py) : 라운드 로빈 조준 접근 경로와 스케줄링 LED 흐름 변경 - +1,+1 -> 대기 -> 조준점 경로 적용, 첫타깃만 2초 나머지는 0.3초대기해야 경로 맞음
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2026-03-28 fix(led_filter.py) : led 필터 ROI 범위와 값 수정 - 위쪽 1/3 + 타겟 내부 상단 1/3 , min_pixels -> 50
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2026-03-28 chore(test.py) : 핫스팟 ip 수정
    [test.py]
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2026-04-02 fix: adaptive pointing 재시도와 스케줄링 접근 제어를 보정
    -Phase 1/2/3 객체 검출 retry, Phase 3 LED/Laser 노출 정리, 첫 타깃만 특수 접근 제어
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2026-05-15 chore : ip 수정
    [test.py]
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2026-09-02 fix: hide scheduling LED probes from normal image routing
    - Stop routing sched_led_* captures after blocking snap notifications
    - Show normalized LED bit state in the preview overlay
    - Clear LED ROI overlay while using compact Slice/ID/BIT text
    - Add router coverage for hidden scheduling LED probe images
